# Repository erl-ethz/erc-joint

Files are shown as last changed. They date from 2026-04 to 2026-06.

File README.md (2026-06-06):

# Elastic Rolling Cam (ERC) Design Repository

This repository contains two alternative ERC design workflows:

- the original MATLAB implementation in [`matlab/`](matlab),
- the Python port in [`erc_design/`](erc_design), extended for simulation and Isaac Lab integration.

They implement the same ERC design idea, but they target different use cases. The MATLAB side remains the original lab workflow for design and manufacturing. The Python side is the integration-oriented workflow for optimization loops, repair, export, and downstream simulation wrappers.

The ERC concept and design methodology are described in:

> Wu, Rui, Luca Girardi, and Stefano Mintchev. "Encoding mechanical intelligence using ultraprogrammable joints." *Science Advances* 11.17 (2025): eadv2052.

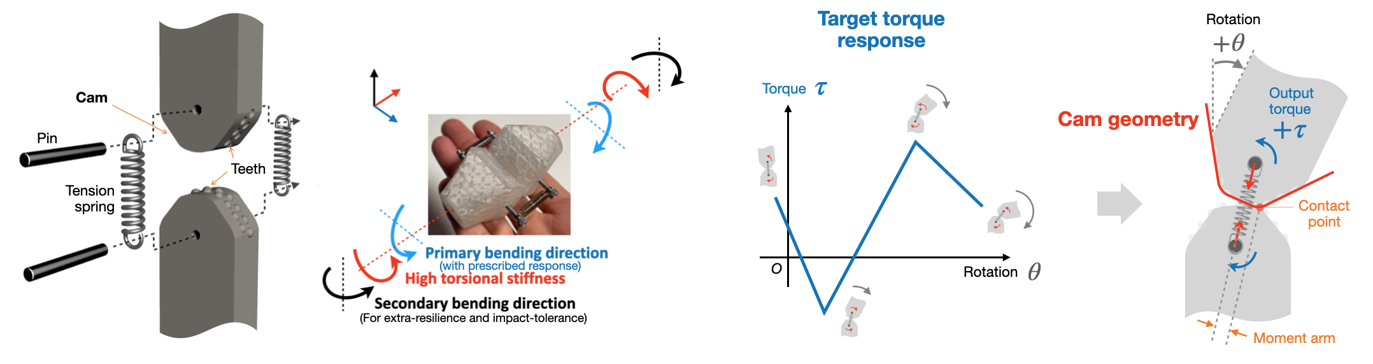
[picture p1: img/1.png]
ERC Diagram


## Repository Layout

```text
.
├── matlab/                     original MATLAB workflow and sensorized utilities
│   ├── Step1_SpringSelector.m
│   ├── Step2_ERCdesigner.m
│   ├── Step3_ERCmodeller.m
│   ├── repair_support_function.m
│   ├── ERC_model.mlx
│   ├── ERC_model.md
│   ├── ERC_demo.m
│   ├── arduino/ERC_sensorised.ino
│   └── README.md
├── erc_design/                 torch-native Python ERC implementation
├── examples/                   Python examples and Isaac Lab entrypoints
├── configs/                    spring catalog and example configs
├── results/                    Python-generated outputs
├── img/                        figures used in the documentation
├── ISAAC_LAB_INTEGRATION.md    Python integration notes
└── CITATION.cff
```

## Choosing A Workflow

Use the MATLAB workflow if you want:

- the original end-to-end design process as developed in the lab,
- the live-script formulation and script-based manufacturing flow,
- the sensorized ERC scripts and Arduino demo.

Use the Python workflow if you want:

- a programmable API instead of an interactive script flow,
- repaired support functions and exportable simulator-facing torque tables,
- function-defined or point-wise ERC profiles for Isaac Lab integration,
- wrappers around downstream simulation repositories.

The two workflows are alternatives. You do not need the Python package to run the MATLAB scripts, and you do not need MATLAB to use the Python API.

## Python Workflow

The Python package reproduces the support-function ERC formulation from the MATLAB workflow and exposes it as reusable classes and helpers:

- `Spring` and `SpringCatalog` load spring definitions from [`configs/springs.yaml`](configs/springs.yaml).
- `PiecewiseLinearTorqueProfile` stores target torque knots.
- `ERCDesigner` converts a target torque profile into a realizable cam profile.
- `ERCDesignResult` stores repaired and unrepaired radii, curvature, cam geometry, and the final output torque table.
- `build_erc_design()` and `build_erc_torque_table()` are simple simulator-facing entry points.
- `build_erc_design_from_function()` and `build_erc_torque_table_from_function()` accept analytic torque functions, negate them internally into ERC sign convention, and export Isaac-facing repaired outputs.

The generated output torque table always has columns:

```text
[joint_angle_rad, torque_nm]
```

### Python Quick Start

Minimal dependencies:

- `torch`
- `PyYAML`

The interactive example also uses:

- `matplotlib`
- `tkinter`

Example setup:

```bash
python -m venv .venv
source .venv/bin/activate
pip install torch pyyaml matplotlib
```

Minimal usage:

```python
import math

from erc_design import ERCDesignConfig, ERCDesigner, PiecewiseLinearTorqueProfile, SpringCatalog

spring = SpringCatalog.from_yaml("configs/springs.yaml")["durovis_0.9x6.1x21"]
profile = PiecewiseLinearTorqueProfile.from_xy(
    [-math.pi / 2.0, 0.0, math.pi / 2.0],
    [0.25, 0.0, -0.25],
)

designer = ERCDesigner(
    spring,
    ERCDesignConfig(
        angle_convention="joint",
        joint_angle_limits_rad=(-math.pi / 2.0, math.pi / 2.0),
    ),
)
result = designer.design(profile, repair=True)
```

Higher-level helper:

```python
from erc_design import build_erc_torque_table

table = build_erc_torque_table(
    [
        (-0.25, -0.25),
        (0.10, 0.10),
        (30.0, 0.0),
        (76.0, 0.0),
        (78.0, 0.2),
    ],
    spring_id="durovis_0.9x6.1x21",
)
```

### Torque Sign Convention

There are two sign conventions in play:

- Isaac Lab / simulator-facing convention: a restoring torque has negative slope around a stable equilibrium.
- Internal ERC design convention: the support-function workflow uses the opposite torque sign.

For this reason, function-defined profiles intended for simulation are negated before entering the ERC designer, and the repaired output is then exported back in the Isaac-facing convention.

Practical rule:

- define the torque law with the physically intuitive Isaac Lab sign,
- do not manually negate it before calling the function-based helpers.

### Python Examples

Interactive editor:

```bash
python3 examples/erc_test.py
```

This GUI lets you:

- edit the requested torque-profile table,
- drag torque knots directly on the plot,
- inspect repaired vs. unrepaired cam geometry,
- export `.sldcrv` and `.xyz` curves.

Function-defined ERC tristable joint-response wrapper:

```bash
python3 examples/erc_tristable_joint_response_example.py --headless
```

This example:

- builds a tristable function-defined ERC profile,
- runs ERC scaling and convexity repair,
- writes repaired torque tables and CAD-oriented cam exports,
- generates a local config for [`erc_isaac/joint_response.py`](erc_isaac/joint_response.py),
- calls [`scripts/convert_concentrated_urdf_yaw_only.py`](scripts/convert_concentrated_urdf_yaw_only.py) if the yaw-only USD is missing,
- recolors the resulting asset with a blue base, orange proximal arms, cyan distal arms, dark joints, and green motors,
- keeps generated videos and analytics outputs under this repository's `results/` tree,
- exposes `--headless`, `--video`, `--analytics`, `--analytics_path`, and `--analytics_fps`,
- renders first-arm analytics with pre/post repair torque profiles, pre/post repair cam profiles, and the moving cam contact point,
- controls analytics legend, axis-label, tick-label, and title sizes through `video.analytics_font_sizes`,
- uses the same playback slow-down for analytics replay as for viewport video, matching the Morphy example behavior.

Point-wise repaired-profile wrapper:

```bash
python3 examples/erc_profile_morphy_example.py --headless
```

This is now a fully local Morphy example derived from the repaired point-wise
profile workflow previously used downstream. It exposes the same main runtime
options locally:

- `--video`
- `--analytics`
- `--analytics_path`
- `--analytics_fps`
- `--analytics_legend_font_size`
- `--analytics_axes_font_size`
- `--analytics_tick_font_size`
- `--analytics_title_font_size`
- `--camera_eye`
- `--camera_target`
- `--results_dir`

All generated outputs stay in this repository by default under
`results/morphy_erc_profile_example/`, including the generated Morphy USD
workspace, PDF reports, cam exports, CSV logs, viewport video, and analytics
video.

More Python integration details are documented in [`ISAAC_LAB_INTEGRATION.md`](ISAAC_LAB_INTEGRATION.md).

## MATLAB Workflow

The original MATLAB implementation is now isolated under [`matlab/`](matlab). Start with [`matlab/README.md`](matlab/README.md).

The core steps are:

1. [`matlab/Step1_SpringSelector.m`](matlab/Step1_SpringSelector.m): derive spring requirements from a target torque profile.
2. [`matlab/Step2_ERCdesigner.m`](matlab/Step2_ERCdesigner.m): synthesize the support function and evaluate the torque response.
3. [`matlab/Step3_ERCmodeller.m`](matlab/Step3_ERCmodeller.m): generate export data and AutoCAD scripts for printable geometry.

The MATLAB subtree also contains:

- [`matlab/repair_support_function.m`](matlab/repair_support_function.m)
- [`matlab/ERC_model.mlx`](matlab/ERC_model.mlx)
- [`matlab/ERC_model.md`](matlab/ERC_model.md)
- [`matlab/ERC_demo.m`](matlab/ERC_demo.m)
- [`matlab/arduino/ERC_sensorised.ino`](matlab/arduino/ERC_sensorised.ino)
- the sensorized modelling scripts and supporting live scripts

The intended usage is to run the MATLAB scripts from the `matlab/` directory so their outputs stay isolated under `matlab/results/`.

## Repair Function

Both workflows include a repair stage for inadmissible support functions. The repair step:

- checks the convexity radius `r + r''`,
- modifies the support function when needed,
- returns repaired torque and cam geometry,
- records whether scaling and/or repair were applied.

Relevant Python outputs in `ERCDesignResult` include:

- `was_scaled`
- `was_repaired`
- `support_radius_m`
- `repaired_support_radius_m`
- `curvature_radius_m`
- `repaired_curvature_radius_m`
- `cam_xy_m`
- `repaired_cam_xy_m`

## Spring Catalog

[`configs/springs.yaml`](configs/springs.yaml) now includes the original entries together with additional springs used during the downstream Python and Isaac integration work.

## Original Design Background

The Elastic Rolling Cam is a rotational joint made of two rolling, spring-loaded cams. By designing the cam geometry appropriately, the joint can approximate a prescribed nonlinear stiffness or torque-angle relationship.

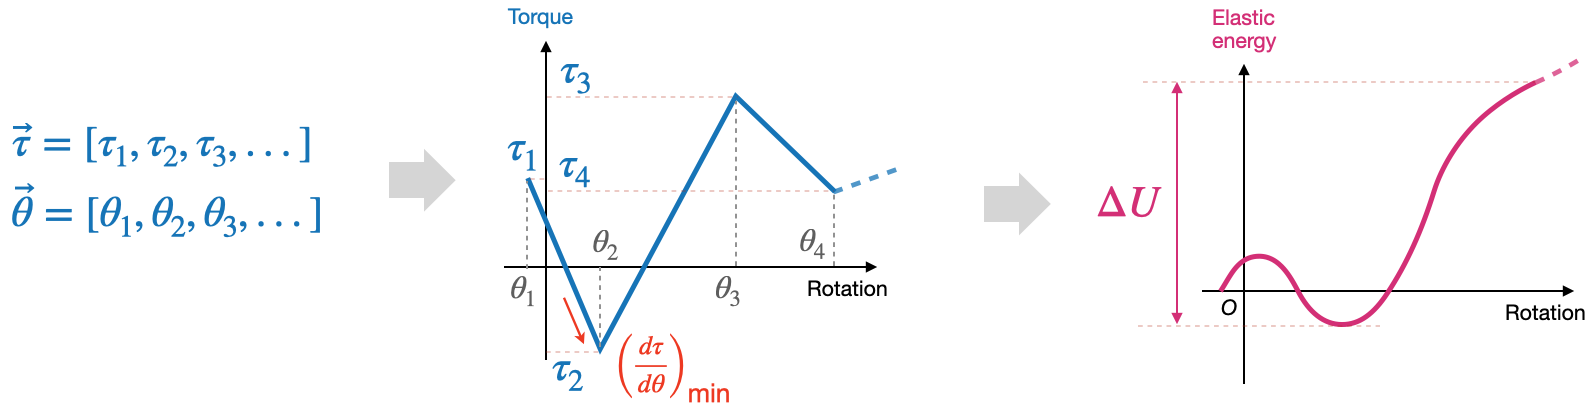
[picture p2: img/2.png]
Torque Response


The original design method chooses spring parameters so the spring can realize both:

- the required maximum torque reduction rate,
- the required elastic-energy variation.

Choosing a larger safety factor improves matching accuracy at the cost of larger joint size.

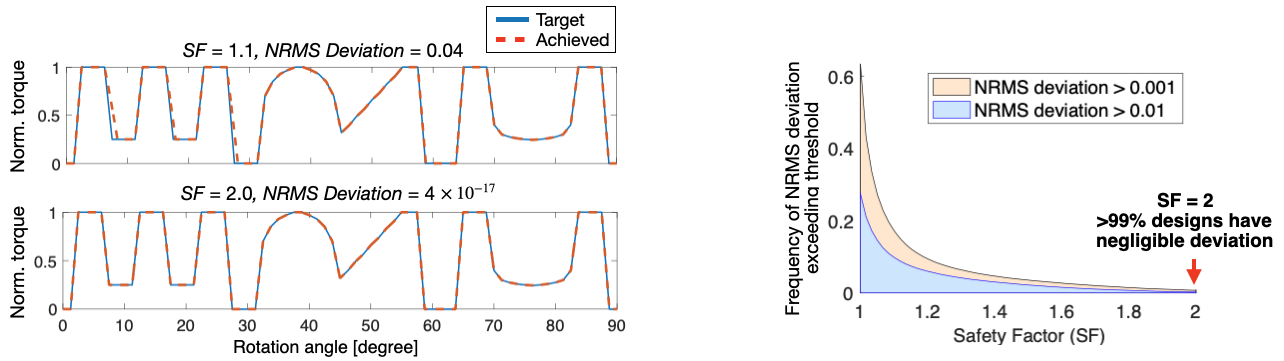
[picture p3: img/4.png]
Design Chart


## Contributors

- Rui Wu ([@wurui1991](https://github.com/wurui1991)): original ERC repository and MATLAB workflow.
- Luca Girardi ([@lucagirardi](https://github.com/lucagirardi)): Python port, repair-oriented updates, Isaac integration, and documentation updates.
- Gabriel Maquignaz ([@gabmaquignaz](https://github.com/gabmaquignaz)): MATLAB, repair-oriented, and integration-related updates.
- Etor Arza Gonzalez ([@EtorArza](https://github.com/EtorArza)): downstream simulation and airframe-integration contributions.

## Citation

If you use the repository, the ERC formulation, or derived content in academic work, please cite:

```text
Wu, Rui, Luca Girardi, and Stefano Mintchev.
"Encoding mechanical intelligence using ultraprogrammable joints."
Science Advances 11.17 (2025): eadv2052.
```

A machine-readable citation is provided in [`CITATION.cff`](CITATION.cff).

## License

This repository is released under the MIT License with the copyright notice attributed to Environmental Robotics Lab in [`LICENSE`](LICENSE).

## Acknowledgment

This work is funded by the European Union's Horizon Europe research and innovation programme under the project SPEAR (Grant No. 101119774), the Swiss National Science Foundation (SNSF) under the Eccellenza Grant (Grant No. 186865), and the ETH Zurich Research Grants (Grant No. ETH-15 20-2).

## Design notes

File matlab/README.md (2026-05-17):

# MATLAB ERC Workflow

This directory contains the original MATLAB ERC implementation. It is an alternative to the Python package in the repository root, not a dependency of it.

Use this workflow if you want the original lab design path based on scripts and live scripts rather than the newer Python API.

If you want to read the mathematical derivation directly on GitHub, use
[`ERC_model.md`](ERC_model.md). If you want the original interactive live-script
version, use [`ERC_model.mlx`](ERC_model.mlx).

## Directory Contents

- [`Step1_SpringSelector.m`](Step1_SpringSelector.m): spring sizing and target-response preparation.
- [`Step2_ERCdesigner.m`](Step2_ERCdesigner.m): support-function design and torque reconstruction.
- [`Step3_ERCmodeller.m`](Step3_ERCmodeller.m): CAD-oriented export and AutoCAD script generation.
- [`repair_support_function.m`](repair_support_function.m): support-function repair utility.
- [`ERC_model.mlx`](ERC_model.mlx): original live-script formulation and derivation.
- [`ERC_model.md`](ERC_model.md): GitHub-readable markdown version of the derivation.
- [`ERC_demo.m`](ERC_demo.m): sensorized ERC real-time visualization.
- [`arduino/ERC_sensorised.ino`](arduino/ERC_sensorised.ino): Arduino sketch used with the sensorized demo.
- [`ERCscr.m`](ERCscr.m), [`ERCscr_sensorised_concave.m`](ERCscr_sensorised_concave.m), [`ERCscr_sensorised_convex_potentiometer.m`](ERCscr_sensorised_convex_potentiometer.m): AutoCAD script helpers.

## Recommended Usage

Run MATLAB from this `matlab/` directory, or add this directory to the MATLAB path before running the scripts. That keeps relative script calls and output paths consistent.

Typical sequence:

1. Run [`Step1_SpringSelector.m`](Step1_SpringSelector.m).
2. Run [`Step2_ERCdesigner.m`](Step2_ERCdesigner.m).
3. Run [`Step3_ERCmodeller.m`](Step3_ERCmodeller.m).

Outputs are intended to be written under [`results/`](results).

## Sensorized Variant

The sensorized ERC files remain in this subtree as part of the MATLAB-oriented workflow:

- use [`ERC_demo.m`](ERC_demo.m) together with [`arduino/ERC_sensorised.ino`](arduino/ERC_sensorised.ino),
- use the `ERCscr_sensorised_*` scripts when generating the sensorized CAD variant.

## Relation To The Python Workflow

The root-level Python workflow provides:

- a torch-native API,
- function-defined and point-wise ERC helpers,
- a repair-aware integration layer,
- Isaac Lab-facing wrappers and export utilities.

If that is what you need, return to the root [`README.md`](../README.md) and [`ISAAC_LAB_INTEGRATION.md`](../ISAAC_LAB_INTEGRATION.md).

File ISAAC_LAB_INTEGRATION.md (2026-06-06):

# ERC Python API Reference

This note documents the Python ERC workflow only. The original MATLAB workflow
now lives under [`matlab/`](matlab) and is documented separately in
[`matlab/README.md`](matlab/README.md).

The MATLAB and Python implementations are alternative entrypoints. Use this
document when you want the torch-native API and the Isaac Lab-facing wrappers.

## High-Level Helpers

The repository now also exposes a small integration layer for common
simulation-facing operations:

```python
from erc_design import (
    build_erc_design,
    build_erc_design_from_function,
    build_erc_torque_table,
    build_erc_torque_table_from_function,
)
```

`build_erc_design(...)`
  Accepts torque knots as `(angle_deg, torque_nm)` pairs, loads the selected
  spring from the YAML catalog, runs the standard joint-angle ERC design
  pipeline, and returns an `ERCDesignResult`.

`build_erc_torque_table(...)`
  Runs the same pipeline and returns only the output torque table with columns
  `[joint_angle_rad, torque_nm]`.

`build_erc_design_from_function(...)`
  Accepts a `FunctionTorqueProfileConfig`, discretizes the requested torque
  function, negates it into the internal ERC sign convention, and then runs
  the full ERC design pipeline including repair.

  Optional argument:
  `max_torque_rmse_nm`
    Raise an error if the repaired ERC torque deviates from the requested
    profile by more than this RMSE threshold.

`build_erc_torque_table_from_function(...)`
  Returns only the repaired Isaac-ready torque table derived from a
  function-defined torque law.

`torque_table_to_function_string(...)`
  Serializes a generated torque table into a torch-callable Python function
  string for downstream pipelines that expect inline code instead of a tensor.

## Function-Defined Profiles

For tristable or otherwise analytic profiles, the repository exposes:

```python
from erc_design import FunctionTorqueProfileConfig, build_function_profile
```

Supported function modes are:

```text
sin
cos
tan
expression
saturating_dual_stiffness
```

Example:

```python
from erc_design import (
    FunctionTorqueProfileConfig,
    build_erc_torque_table_from_function,
)

table = build_erc_torque_table_from_function(
    FunctionTorqueProfileConfig(
        name="expression",
        expression="-0.4 * sin(2*pi*theta) - 0.1 * tan(theta * 0.96)",
        angle_min_rad=-1.48,
        angle_max_rad=1.48,
        num_samples=400,
    ),
)
```

This is the preferred way to port a function-defined programmable-joint law
from Isaac Lab into a realizable ERC approximation, because the output is
always passed through ERC energy scaling and convexity repair before export.

Sign convention note:

- define the input function in the same sign convention you want in Isaac Lab,
- do not negate it manually,
- the integration helpers negate it internally before calling `ERCDesigner`,
- the exported `output_torque_table` is again Isaac-facing.

## External Joint-Response Simulation

The example script

```python
examples/erc_tristable_joint_response_example.py
```

does not implement a separate local mock simulator. Instead, it prepares a
repaired ERC response and then launches the local test harness:

```python
erc_isaac/joint_response.py
```

Workflow:

1. Build the repaired ERC torque table from the configured tristable function.
2. Generate a `joint_response.py` YAML config with `joint_response.mode=piecewise`
   and the repaired ERC table as the piecewise response.
3. If the required yaw-only USD asset is missing, call:

```python
scripts/convert_concentrated_urdf_yaw_only.py
```

4. Launch the local `joint_response.py` simulation with the generated config.

The wrapper also writes a recommended `test.torque_z` based on the repaired ERC
peak passive torque so the applied load in the Isaac Lab test is scaled to a
reasonable level.

The wrapper exposes runtime options such as `--headless`, `--video`,
`--analytics`, `--analytics_path`, and `--analytics_fps`. It writes the final
video and analytics paths into the generated config as absolute paths under
this repository's `results/` tree, and the analytics replay uses the same
playback slow-down as the viewport video. Any remaining unknown CLI options
are also forwarded.

The analytics use the first arm and include pre/post repair torque profiles,
pre/post repair cam profiles, and the moving cam contact point. Configure
legend, axis-label, tick-label, and title sizes under
`video.analytics_font_sizes`.

After asset generation, the wrapper also recolors the yaw-only USD locally so:

- the main base is blue,
- `arm_segment_1_*` (non-folding / proximal) is orange,
- `arm_segment_2_*` (folding / distal) is yellow,
- joints are dark gray and motors are green.

## Local Morphy Example

The repository also exposes a second standalone example:

```text
examples/erc_profile_morphy_example.py
```

This local script implements:

- repaired point-wise ERC profile generation,
- fixed-base Morphy simulation,
- viewport video recording,
- analytics video export.

The local wrapper exposes the main runtime options directly:

- `--headless`
- `--video`
- `--analytics`
- `--analytics_path`
- `--analytics_fps`
- `--analytics_legend_font_size`
- `--analytics_axes_font_size`
- `--analytics_tick_font_size`
- `--analytics_title_font_size`
- `--camera_eye`
- `--camera_target`
- `--results_dir`

All outputs are written locally under `results/morphy_erc_profile_example/`
unless `--results_dir` is overridden.

## SpringCatalog

```python
catalog = SpringCatalog.from_yaml(path)
spring = catalog[spring_id]
```

Arguments:

```text
path
  YAML file containing a top-level `springs:` list.

spring_id
  String ID of the spring entry to use.
```

Expected YAML fields per spring:

```yaml
springs:
  - id: example_spring
    description: Optional human-readable description
    material: Optional material name
    wire_diameter_m: 0.001
    external_diameter_m: 0.006
    free_length_m: 0.021
    max_length_m: 0.040
    max_extension_m: 0.0125
    tension_at_rest_n: 0.8
    maximum_load_n: 21.88
    spring_constant_n_per_m: 1750.0
    count: 1
```

Required fields:

```text
id
max_length_m
max_extension_m
tension_at_rest_n
spring_constant_n_per_m
```

Optional fields:

```text
description
material
wire_diameter_m
external_diameter_m
free_length_m
maximum_load_n
count
```

All values are SI units.

## PiecewiseLinearTorqueProfile

```python
profile = PiecewiseLinearTorqueProfile.from_xy(
    angles_rad,
    torques_nm,
)
```

Arguments:

```text
angles_rad
  1D tensor-like sequence of strictly increasing profile knot angles.

torques_nm
  1D tensor-like sequence of torque values at those knots.
```

Output:

```text
PiecewiseLinearTorqueProfile
  Stores knots as a torch tensor shaped `(n_points, 2)` with columns
  `[angle_rad, torque_nm]`.
```

Notes:

```text
The angle convention is interpreted later by ERCDesignConfig.
Use joint-angle knots when angle_convention="joint".
Use cam-angle knots when angle_convention="cam".
```

## ProfileParameterization

```python
param = ProfileParameterization(
    n_segments=5,
    angle_bounds_rad=None,
    fixed_start_torque_nm=None,
    fixed_end_torque_nm=None,
    sort_angles=True,
)

profile = param.decode(parameters)
```

Constructor arguments:

```text
n_segments
  Number of piecewise-linear segments. Default is 5, giving 6 knots.

angle_bounds_rad
  Optional `(min_angle, max_angle)` tuple. If provided, endpoint angles are
  fixed and the parameter vector contains only interior angles.

fixed_start_torque_nm
  Optional fixed torque at the first knot.

fixed_end_torque_nm
  Optional fixed torque at the last knot.

sort_angles
  If true, angle parameters are sorted before profile construction.
```

Parameter-vector layout:

```text
[all angle parameters, all free torque parameters]
```

Parameter counts for the default 5-segment profile:

```text
Free x-y profile:
  6 angles + 6 torques = 12 parameters

Fixed endpoint torques:
  6 angles + 4 torques = 10 parameters

Fixed angle bounds and fixed endpoint torques:
  4 interior angles + 4 interior torques = 8 parameters
```

Output:

```text
PiecewiseLinearTorqueProfile
```

## ERCDesignConfig

```python
config = ERCDesignConfig(
    n_grid=1000,
    safety_factor=1.1,
    convexity_eps_m=1e-3,
    energy_scale_eps=1e-6,
    angle_convention="joint",
    joint_angle_limits_rad=(-math.pi / 2.0, math.pi / 2.0),
    angle_limit_tolerance_rad=1e-7,
    energy_reference_angle_rad=0.0,
    invert_output_torque=True,
)
```

Arguments:

```text
n_grid
  Number of samples used for energy integration, repair, cam generation, and
  output table generation.

safety_factor
  Spring safety factor applied to usable extension/energy.

convexity_eps_m
  Minimum allowed curvature radius target used by the repair solve.

energy_scale_eps
  Small margin subtracted when the energy profile must be scaled down.

angle_convention
  "joint" if profile angles are joint angles.
  "cam" if profile angles are single-cam angles.

joint_angle_limits_rad
  Hard joint-angle limits. Default is `[-pi/2, pi/2]`.
  In cam convention, profile input angles are checked against half of this
  interval.

angle_limit_tolerance_rad
  Numerical tolerance for accepting boundary angles.

energy_reference_angle_rad
  Joint angle at which integrated energy is shifted to zero.

invert_output_torque
  If true, the returned output torque table is sign-inverted for downstream use.
```

## ERCDesigner

```python
designer = ERCDesigner(spring, config)
result = designer.design(profile, repair=True)
```

Constructor arguments:

```text
spring
  Spring object loaded from SpringCatalog.

config
  ERCDesignConfig. If omitted, defaults are used.
```

`design(...)` arguments:

```text
profile
  PiecewiseLinearTorqueProfile.

repair
  If true, profiles with negative `r + r''` are repaired using the finite-
  difference support-function repair.
```

Output:

```text
ERCDesignResult
```

## ERCDesignResult

Main fields:

```text
input_profile
  Original PiecewiseLinearTorqueProfile.

output_torque_table
  Torch tensor shaped `(n_grid, 2)`.
  Columns are `[joint_angle_rad, torque_nm]`.
  Torque is sign-inverted if `invert_output_torque=True`.

target_torque_nm
  Requested torque sampled on the internal grid, before energy scaling and
  repair.

scaled_torque_nm
  Torque after energy scaling.

repaired_torque_nm
  Torque after convexity repair. This is before optional output sign inversion.

cam_xy_m
  Pre-repair cam profile coordinates in meters.

repaired_cam_xy_m
  Final admissible cam profile coordinates in meters.

support_radius_m
  Pre-repair support function radius.

repaired_support_radius_m
  Final support function radius.

curvature_radius_m
  Pre-repair `r + r''`.

repaired_curvature_radius_m
  Final `r + r''`.

alpha
  Energy scaling factor. `1.0` means no energy scaling.

was_scaled
  True if the profile exceeded spring energy limits and was scaled.

was_repaired
  True if convexity repair was applied.

torque_rmse_nm
  RMSE between requested sampled torque and final repaired torque before output
  sign inversion.
```

Export methods:

```python
result.export_xyz(path, repaired=True, n_points=None)
result.export_sldcrv(path, repaired=True, n_points=None)
```

Arguments:

```text
path
  Output file path.

repaired
  If true, export the final repaired cam profile.
  If false, export the pre-repair cam profile.

n_points
  Optional number of points to export. If omitted, the curve is resampled to
  twice the internal grid length.
```

Output format:

```text
x_mm y_mm z_mm
```

The design computations use SI units and radians. Export files are converted to
millimeters for CAD import.

## Torque Table To Callable String

If a downstream system needs a torch-callable code string rather than a tensor,
the output table can be serialized with:

```python
def torque_table_to_function_string(table, fn_name: str) -> str:
    table = table.detach().cpu()
    angles = [float(v) for v in table[:, 0]]
    torques = [float(v) for v in table[:, 1]]
    if fn_name not in {"torque_fn_left", "torque_fn_right"}:
        raise ValueError(fn_name)

    return f"""
_erc_angles = {angles!r}
_erc_torques = {torques!r}
_erc_cache = {{}}
def {fn_name}(x):
    key = (str(x.device), x.dtype)
    if key not in _erc_cache:
        _erc_cache[key] = (
            torch.tensor(_erc_angles, device=x.device, dtype=x.dtype),
            torch.tensor(_erc_torques, device=x.device, dtype=x.dtype),
        )
    xp, fp = _erc_cache[key]
    q = torch.clamp(x, xp[0], xp[-1])
    idx = torch.searchsorted(xp, q, right=True) - 1
    idx = torch.clamp(idx, 0, xp.numel() - 2)
    x0 = xp[idx]
    x1 = xp[idx + 1]
    y0 = fp[idx]
    y1 = fp[idx + 1]
    return y0 + (q - x0) / (x1 - x0) * (y1 - y0)
"""
```

Inputs:

```text
table
  `ERCDesignResult.output_torque_table`.

fn_name
  Function name to define in the string.
```

Output:

```text
Python code string defining a torch function with the given name.
```

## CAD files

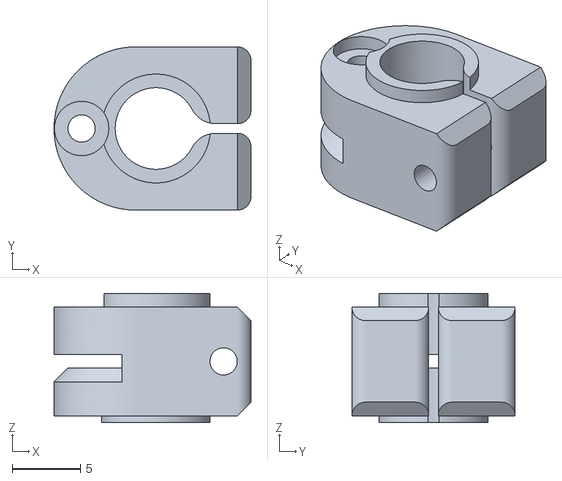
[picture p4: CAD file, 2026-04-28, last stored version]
Coupler.stl
14.5 x 12.0 x 9.50

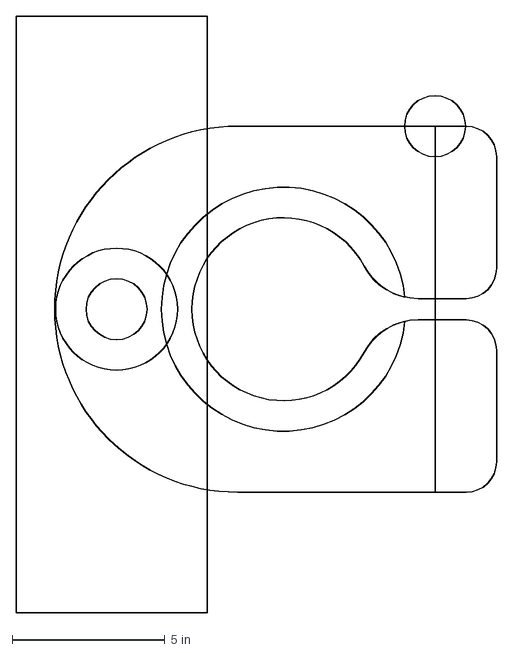
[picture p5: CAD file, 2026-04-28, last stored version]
Coupler_2D.dxf
15.7 x 19.6 in

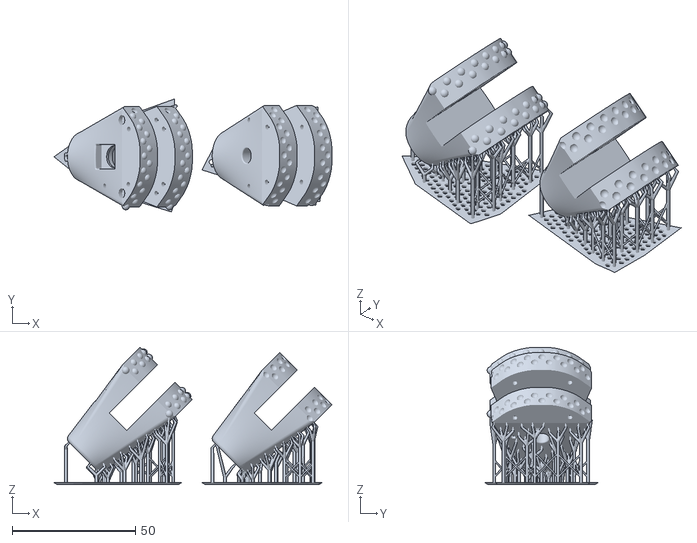
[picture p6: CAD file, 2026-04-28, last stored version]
Cam_example_Print.stl
112.9 x 45.8 x 55.7

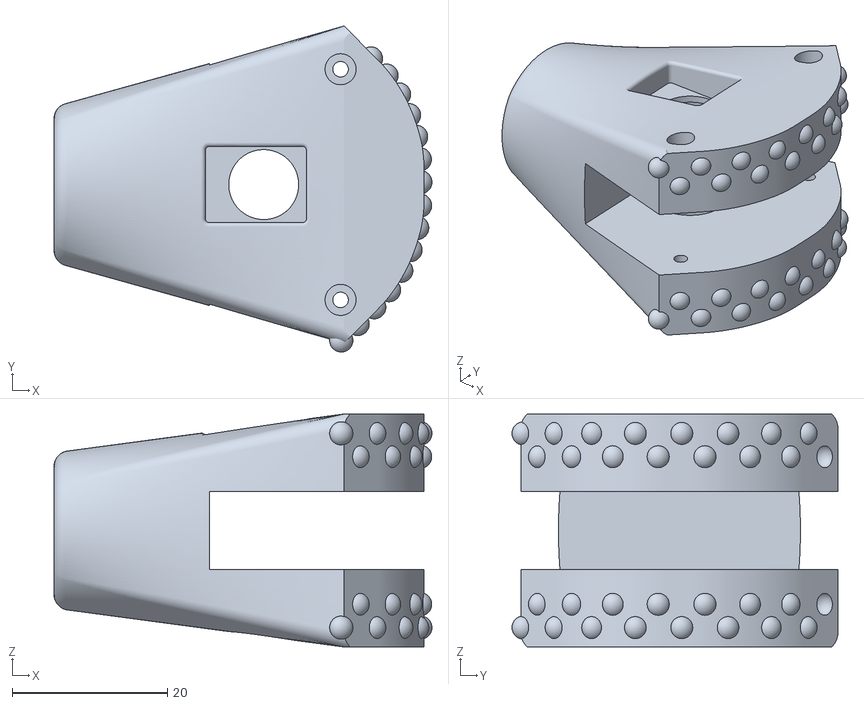
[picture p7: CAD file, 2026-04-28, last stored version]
Cam1_example.stl
48.7 x 42.0 x 30.0

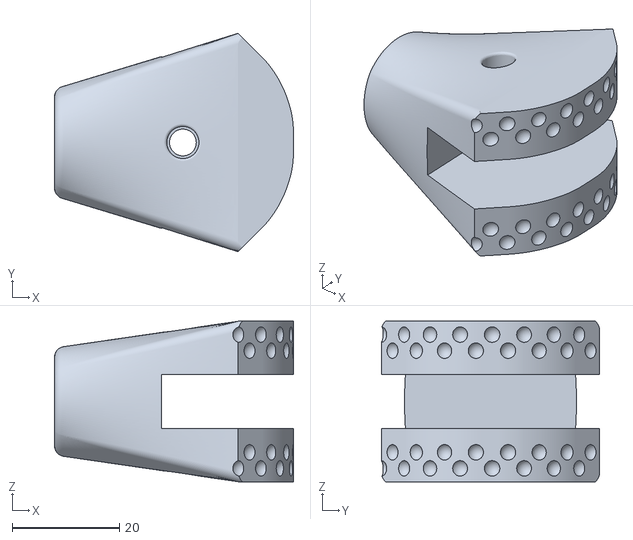
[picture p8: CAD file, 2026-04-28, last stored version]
Cam2_example.stl
44.7 x 40.8 x 30.0

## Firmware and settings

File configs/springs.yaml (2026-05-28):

springs:
  - id: durovis_0.9x6.1x21
    description: durovis spring d = 0.9 mm, D_e = 6.1 mm, L_0 = 21 mm, stainless steel
    material: stainless steel
    wire_diameter_m: 0.9e-3
    external_diameter_m: 6.1e-3
    free_length_m: 21e-3
    max_length_m: 40e-3
    max_extension_m: 12.5e-3
    tension_at_rest_n: 0.8
    maximum_load_n: 21.88
    spring_constant_n_per_m: 1.75e3
    count: 1
  - id: sodemann_E03000491250M
    description: Spring from Sodemann E03000491250M https://www.industrial-springs.com/e03000491250m; d = 1.24 mm, D_e = 7.62 mm, L_0 = 25 mm, music wire  
    material: music wire
    wire_diameter_m: 1.24e-3
    external_diameter_m: 7.62e-3
    free_length_m: 31.75e-3
    max_length_m: 42.42e-3
    max_extension_m: 10.67e-3
    tension_at_rest_n: 6.23
    maximum_load_n: 69.39
    spring_constant_n_per_m: 5.94e3
    count: 1
  - id: sodemann_E02400411250S
    description: Spring from Sodemann E02400411250S https://www.industrial-springs.com/e02400411250s; d = 1.04 mm, D_e = 6.10 mm, L_0 = 31.75 mm, stainless steel
    material: stainless steel 302
    wire_diameter_m: 1.04e-3
    external_diameter_m: 6.10e-3
    free_length_m: 31.75e-3
    max_length_m: 42.67e-3
    max_extension_m: 10.92e-3
    tension_at_rest_n: 3.89
    maximum_load_n: 43.17
    spring_constant_n_per_m: 3.57e3
    count: 1
  - id: sodemann_E03600551250M
    description: Spring from Sodemann E03600551250M https://www.industrial-springs.com/e03600551250m; d = 1.40 mm, D_e = 9.14 mm, L_0 = 31.75 mm, music wire
    material: music wire
    wire_diameter_m: 1.40e-3
    external_diameter_m: 9.14e-3
    free_length_m: 31.75e-3
    max_length_m: 42.16e-3
    max_extension_m: 10.41e-3
    tension_at_rest_n: 7.12
    maximum_load_n: 78.29
    spring_constant_n_per_m: 6.76e3
    count: 1
  - id: sodemann_31570
    description: Spring from Sodemann 31570 https://www.industrial-springs.com/31570; d = 1.00 mm, D_e = 7.00 mm, L_0 = 19.00 mm, music wire
    material: music wire
    wire_diameter_m: 1.00e-3
    external_diameter_m: 7.00e-3
    free_length_m: 19.00e-3
    max_length_m: 27.17e-3
    max_extension_m: 8.17e-3
    tension_at_rest_n: 6.82
    maximum_load_n: 45.30
    spring_constant_n_per_m: 4.71e3
    count: 1
  - id: sodemann_41570-316
    description: Spring from Sodemann 41570-316 https://www.sodemann-federn.de/41570-316; d = 1.00 mm, D_e = 7.00 mm, L_0 = 19.00 mm, stainless steel 316
    material: stainless steel 316
    wire_diameter_m: 1.00e-3
    external_diameter_m: 7.00e-3
    free_length_m: 19.00e-3
    max_length_m: 27.17e-3
    max_extension_m: 8.17e-3
    tension_at_rest_n: 5.67
    maximum_load_n: 37.70
    spring_constant_n_per_m: 3.92e3
    count: 1
  - id: durovis_0.5x3.5x15.2_C
    description: Spring from Durovis 0.5x3.5x15.2_C https://www.durovis.ch/en/05-1-1.html; d = 0.5 mm, D_e = 3.5 mm, L_0 = 15.2 mm, steel grade C
    material: steel grade C
    wire_diameter_m: 0.5e-3
    external_diameter_m: 3.5e-3
    free_length_m: 15.2e-3
    max_length_m: 30.27e-3
    max_extension_m: 15.07e-3
    tension_at_rest_n: 0.94
    maximum_load_n: 18.82
    spring_constant_n_per_m: 1.19e3
    count: 1

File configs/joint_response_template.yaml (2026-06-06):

# Joint response test configuration
# Usage:
#   1) Generate the yaw-only airframe USD + JSON (defaults from this file):
#      python scripts/convert_concentrated_urdf_yaw_only.py --headless \
#          --output_dir cache/workspace_local/my_airframe_yaw_only \
#          --config configs/joint_response_template.yaml
#      (Optional) override params on the CLI:
#      python scripts/convert_concentrated_urdf_yaw_only.py --headless \
#          --output_dir cache/workspace_local/my_airframe_yaw_only \
#          --arm_proximal_length 0.02 --arm_distal_length 0.18 \
#          --base_mass 0.3 --base_inertia 0.0005 0.0005 0.001
#   2) Run the test with this config:
#      python erc_isaac/joint_response.py --headless \
#          --config configs/joint_response_template.yaml

airframe:
  usd_path: cache/workspace_local/my_airframe_yaw_only/concentrated_quadrotor_yaw_only.usd
  airframe_data_path: cache/workspace_local/my_airframe_yaw_only/airframe_data.json

airframe_generation:
  arm_proximal_length: 0.1
  arm_distal_length: 0.1
  base_mass: 0.3
  base_inertia: [0.0005, 0.0005, 0.001]

simulator:
  dt: 0.002
  sim_duration: 1.0
  gravity: [0.0, 0.0, 0.0]
  device: "cuda:0"
  enable_stabilization: false
  soft_endstop:
    enabled: true
    angle_deg: 70.0
    stiffness: 3.0
    damping: 0.05

joint:
  stiffness: 0.3
  damping: 0.01
  # Hard joint limits (sim-level endstops). Set a scalar for symmetric limits or [lower, upper].
  hard_endstop_deg: 90.0

joint_response:
  # mode: linear (use joint.stiffness), piecewise (table), or function (discretized)
  mode: function
  num_samples: 400
  piecewise:
    # List of [angle_rad, torque_Nm]
    points: [[-0.523599, 0.4], [-0.05, 0.3], [0.0, 0.0], [0.05, -0.3], [0.523599, -0.4]]
  function:
    # name: sin, cos, tan, expression (custom expression), saturating_dual_stiffness
    # theta is the joint angle in radians (same as joint_pos).
    name: expression
    # Tristable-style symmetric torque profile over the configured angle range:
    expression: "-0.4 * sin(2*pi*theta) -0.1 * tan(theta*0.96)"
    # Other torque profile examples:
      # expression: "-(sigmoid(10*theta)-0.5)"
      # expression: "-0.125 * (theta + 0.5 * theta**3 + 0.05 * theta**5)"
    angle_min: -1.5
    angle_max: 1.5
    offset: 0.0
    torque_clip: null

test:
  torque_z: 0.55
  # Applies torque_z * torque_directions[i] on motor_names[i]
  motor_names: ["motor_0", "motor_1", "motor_2", "motor_3"]
  torque_directions: [-1.0, 1.0, 1.0, -1.0]
  # Optional time-based schedule of torque scaling (multiplies torque_z).
  # Each entry applies for "duration" seconds. Omit to use a constant scale=1.
  torque_schedule:
    - duration: 0.3
      scale: 0.0
    - duration: 0.03
      scale: 1.0
    - duration: 0.3
      scale: 0.0
    - duration: 0.03
      scale: -1.0
    - duration: 0.3
      scale: 0.0

video:
  # Set to null to disable, or provide a float (e.g., 0.25 = 4x slower)
  playback_speed: null
  path: results/joint_response_animation.mp4
  # Optional analytics video (plots). Set to null to disable.
  analytics_path: results/joint_response_analytics.mp4
  analytics_fps: 60
  analytics_font_sizes:
    legend: 11
    axes: 13
    ticks: 11
    titles: 15

camera:
  # Top-down, closer view (camera_eye is computed from target, distance, yaw_deg, height)
  target: [-0.25, 0.0, 0.0]
  distance: 0.8
  yaw_deg: 0.0
  height: 1.5

output:
  results_dir: results
  plot_name: joint_response_chart.png
  joint_response_plot_name: programmable_joint_response_profile.png

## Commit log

2026-04-28 Initial commit: ERC joint dev files
    [Cam1_example.stl, Cam2_example.stl, Cam_example_Print.stl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]
2026-04-28 Add .gitignore, results/ folder, and update output paths
    - Remove settings.local.json and generated CAD files (stl/dxf/sldcrv) from tracking
    - Add results/ folder (tracked via .gitkeep, contents ignored)
    - Update Step3_ERCmodeller to save cam_profile.sldcrv, convex.scr, concave.scr to results/
    [Cam1_example.stl, Cam2_example.stl, Cam_example_Print.stl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]
2026-05-17 reverted to full tabular angle-torque definition for morphy example
